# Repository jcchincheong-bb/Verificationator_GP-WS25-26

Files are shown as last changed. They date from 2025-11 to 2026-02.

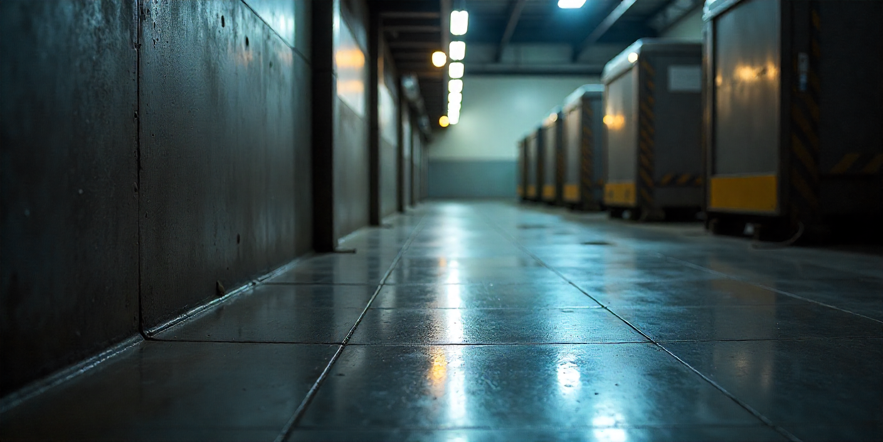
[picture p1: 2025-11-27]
3.8 Interactive Brochure (and Spec Sheet)/assets/bg_factoryfloor.png

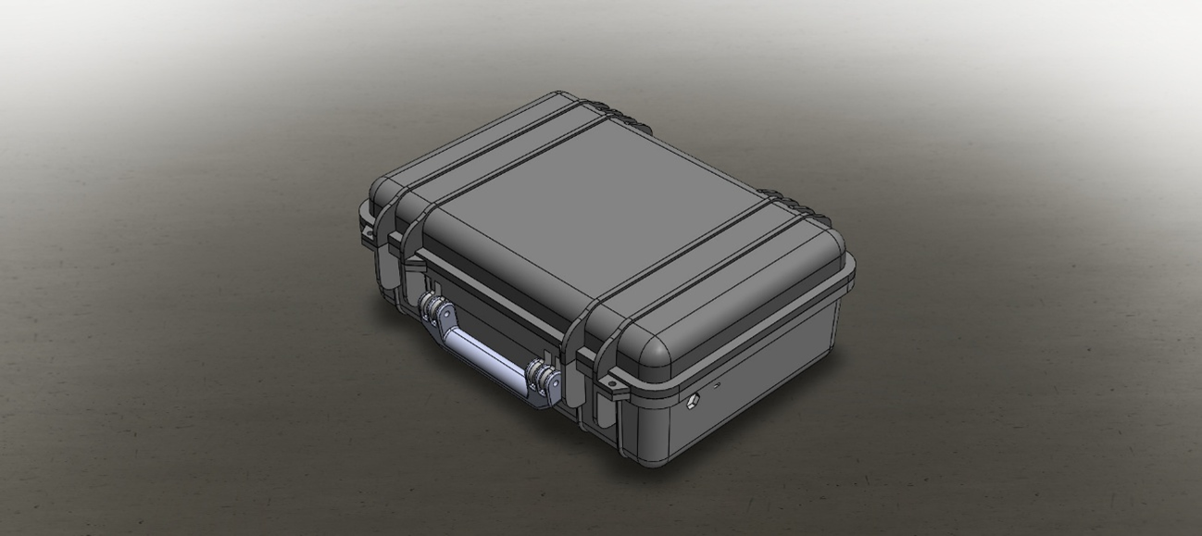
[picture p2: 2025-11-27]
3.8 Interactive Brochure (and Spec Sheet)/assets/PH_case_outside.png

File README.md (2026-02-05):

This project was done as part of the Group Project Module at HSRW in WS25/26. It was done under requirements provided by [Innovatest](https://www.innovatest-europe.com/). 

### Abstract
Product Showcase (https://www.youtube.com/watch?v=Xx_LVumxhoE)

The Verificationator project is focused on the design of a highly portable, robust, and user-friendly solution that allows technicians to verify and calibrate hardness testers directly in the field. The project’s scope spans from the concept design to the project documentation and the design of an interactive brochure. The project spanned from October 5th, 2025, to January 13th, 2026. Five engineering students make up the interdisciplinary design team, and the project was completed under the guidance of Hochschule Rhein-Waal professors and scientific staff.

Initial market analysis revealed that the market for hardness testers is growing and ready for such a portable verification kit. The initial concept proposed a fully integrated system which can operate safely in factory environments, has an ergonomic HMI, and can automatically identify and operate with Innovatest load cell models ranging from 10 gf to 3,000 kgf. The production budget was set to €4,000 per unit, ensuring competitiveness on the market.

From a mechanical standpoint, the device uses an IP-67 rated rugged pelican case with an aluminium chassis mounted inside to house the electronics. Medium density foam inserts surround this chassis to provide shock absorption and padding. Load cells are stored in dedicated foam compartments on the opposite side of the case, allowing secure transport without damage or misalignment. A complete 3D model was constructed to demonstrate all mechanical connections, fasteners, sealants, and other features to create a device that is suited for harsh factory environments. To document the entire mechanical design, a technical assembly drawing was done according to DIN 406.

On the electrical side of the design, a complete schematic diagram and preliminary PCB were designed to match all functionality requirements with the utmost precision and speed. An advanced measurement chain was designed to process the load cell signals and gives a noise-free resolution of 17 bits, classifying as a Class A measuring device by OIML. The design also incorporates high-performance components such as the ESP32-P4, allowing for incredible signal processing and input responsiveness. The control, power management, and battery management circuits were designed to give a battery life of 9.16 hours and advanced features such as switching between 5 V and 10 V excitation and real-time graphing. The complete program logic of the microcontroller is documented in a programming flow chart to illustrate the main settings, interrupts, and other processes.

After a Make or Buy analysis was performed, the pelican case and electrical components were specified in the requirements manual, and the custom-made aluminium and foam interior manufacturing techniques were defined. A complete BOM was then done after careful selection of components. After which, the complete production and assembly plan was defined, revealing a takt time of 756 min/unit and a total production time of 1032 min/unit, suggesting parallel manufacturing or outsourcing may be required. The assembly time, on the other hand, was found to be only 142 min/unit.

Finally, the costs of all the materials, labour, manufacturing, and overheads were considered to calculate a production cost of €3990.15. Accounting for business overheads, profit, and commission, the final offer price was found to be €7018.28.

### Development Team
- [Abhinav Kothari](https://www.linkedin.com/in/abhinav-kothari-2ak/) - Manufacturing and Production Planning, Video Editing
- Ahmad Zeaiter - Mechanical Design, Technical Drawing, Brochure Design
- [Justin Julius Chin Cheong](https://jcchincheong-bb.github.io/) - Project Managment, Market Analysis, Cost Estimation, System Architecture and Signal Conditioning Design
- Wasim Ahmed Mohammed Al Asbahi - Main Electrical Design, Programming Flowchart

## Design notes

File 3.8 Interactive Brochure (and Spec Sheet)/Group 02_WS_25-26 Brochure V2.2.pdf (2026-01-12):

# VERFICATIONATOR

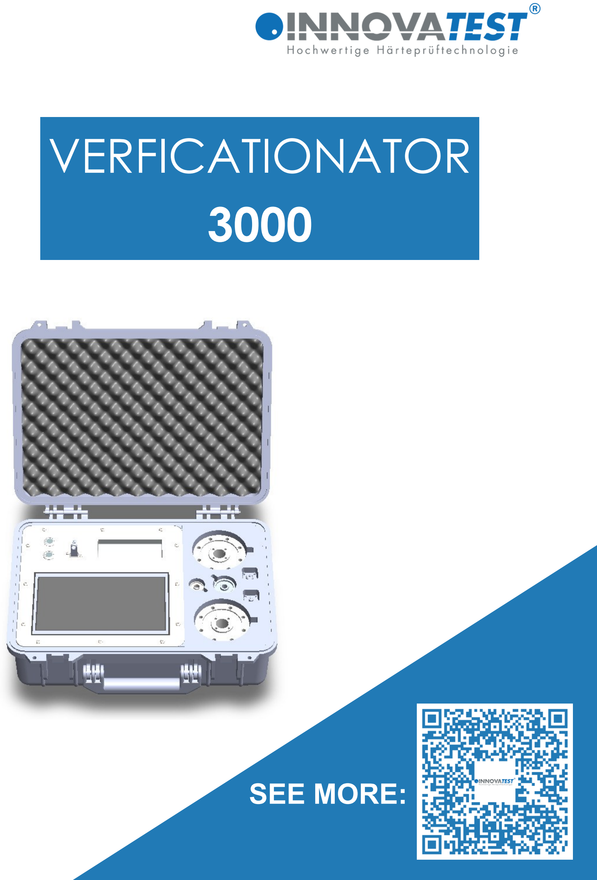
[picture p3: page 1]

3000

# SEE MORE:

The Verificationator 3000 is a premier load cell calibration device that works with 6 load cells, promises incredible precision, low noise and easy to use calibration of the load cells. With such a device, laboratory calibration can become a thing of the past, as with high mobility and rugged design, the kit can be taken to any job site in any conditions to verify the force output of Innovatest hardness testers using Innovatest load cells.

# VERF-3000

# Mobile and Portable

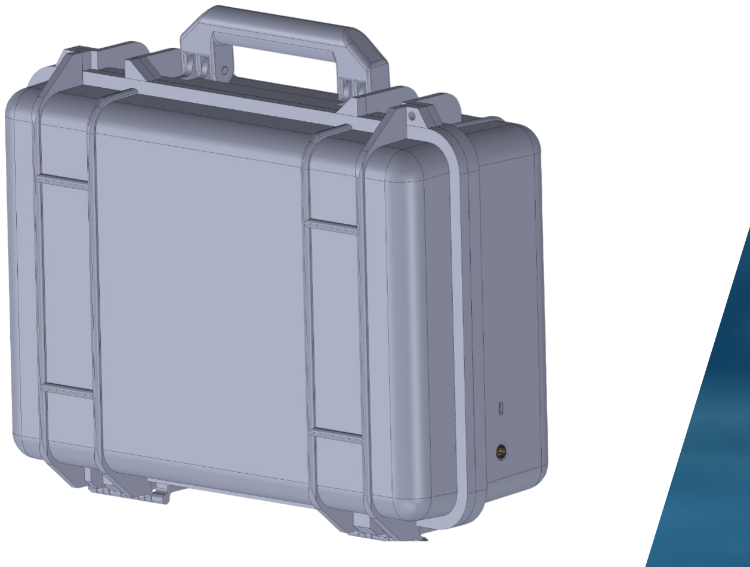
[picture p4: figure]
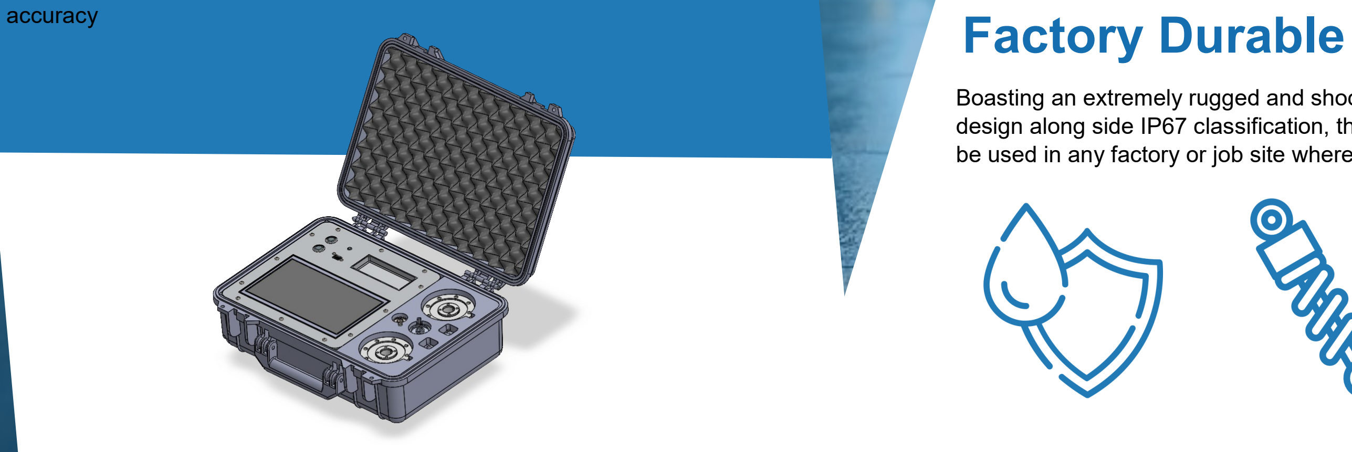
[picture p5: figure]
accuracy; Factory Durable

Boasting an extremely rugged and shock absorbent design along side IP67 classification, the VERF-3000 can be used in any factory or job site where needed.

# The Verificationator 3000

# Extreme Precision

With enough precision to be a OIML Class A load cell measuring device, the VERF-3000 can ensure load cells are calibrated to the upmost precision and

The Verificationator 3000 is mobile and lightweight and can be carried anywhere it is needed.

Weighing only 12kg, it is a revolutionary step in force verification on the go

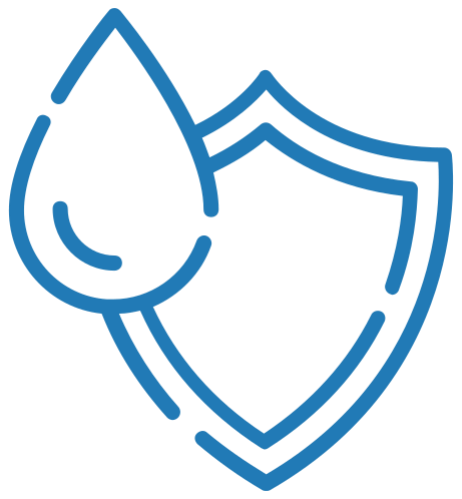
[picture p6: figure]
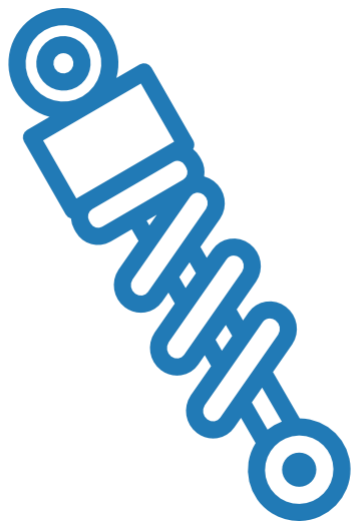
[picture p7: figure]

Main Features The Verificationator 3000 can be easily used to measure the force values for calibration or testing or routine inspections. The data is plotted on a graph and exportable to a USB stick in a CSV format

# TOUCH SCREEN

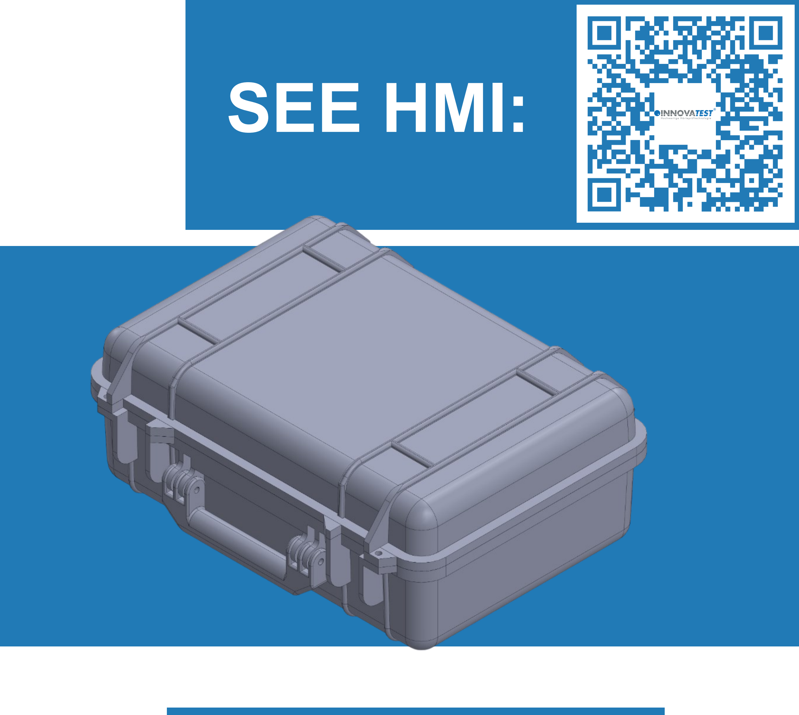
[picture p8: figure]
SEE HMI:

Real-Time Graphing | Export to CSV

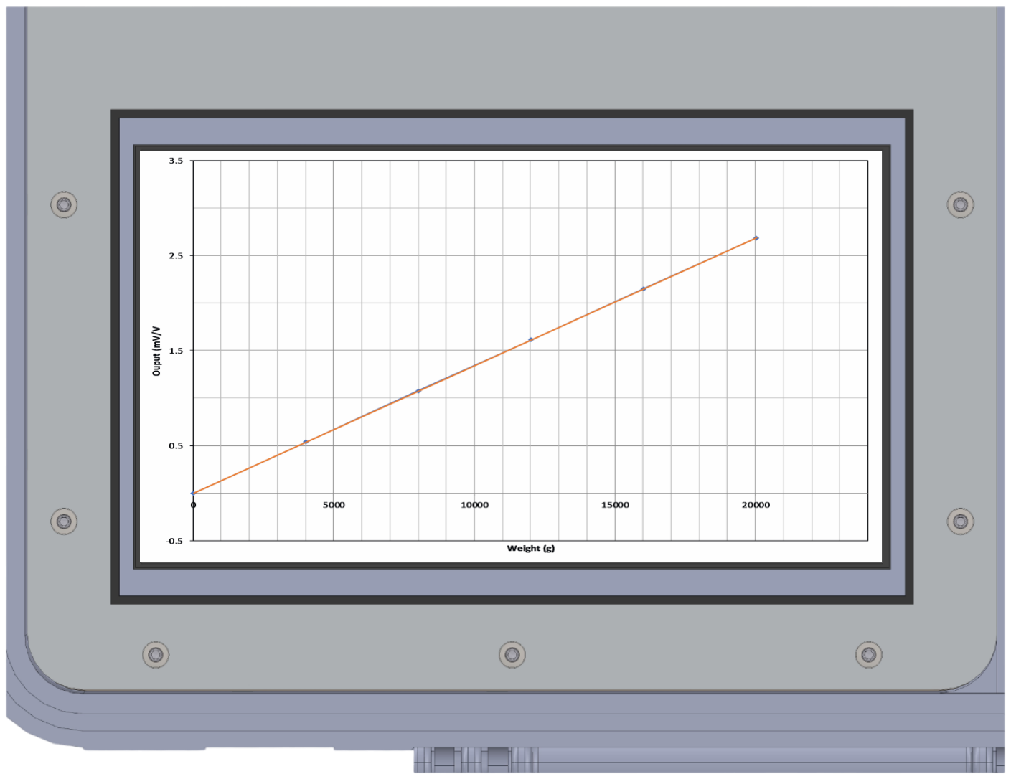
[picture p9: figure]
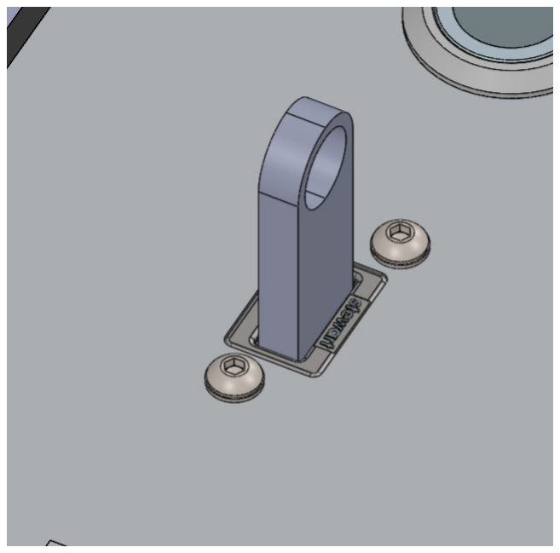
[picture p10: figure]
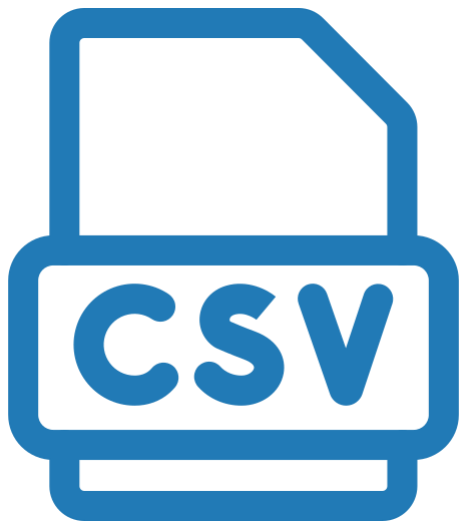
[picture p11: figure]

# Long-lasting & Rechargeable

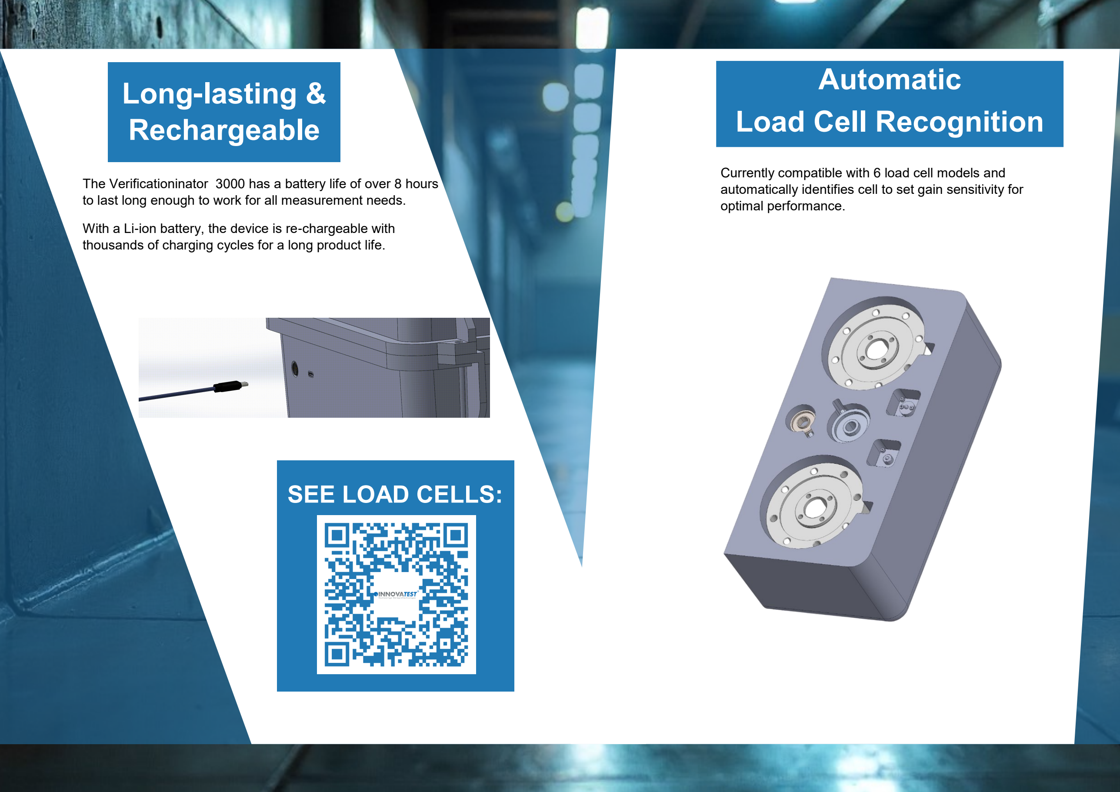
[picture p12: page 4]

The Verificationinator 3000 has a battery life of over 8 hours to last long enough to work for all measurement needs.

With a Li-ion battery, the device is re-chargeable with thousands of charging cycles for a long product life.

Currently compatible with 6 load cell models and automatically identifies cell to set gain sensitivity for optimal performance.

# Automatic Load Cell Recognition

# SEE LOAD CELLS:

# Spec. Sheet STANDARD

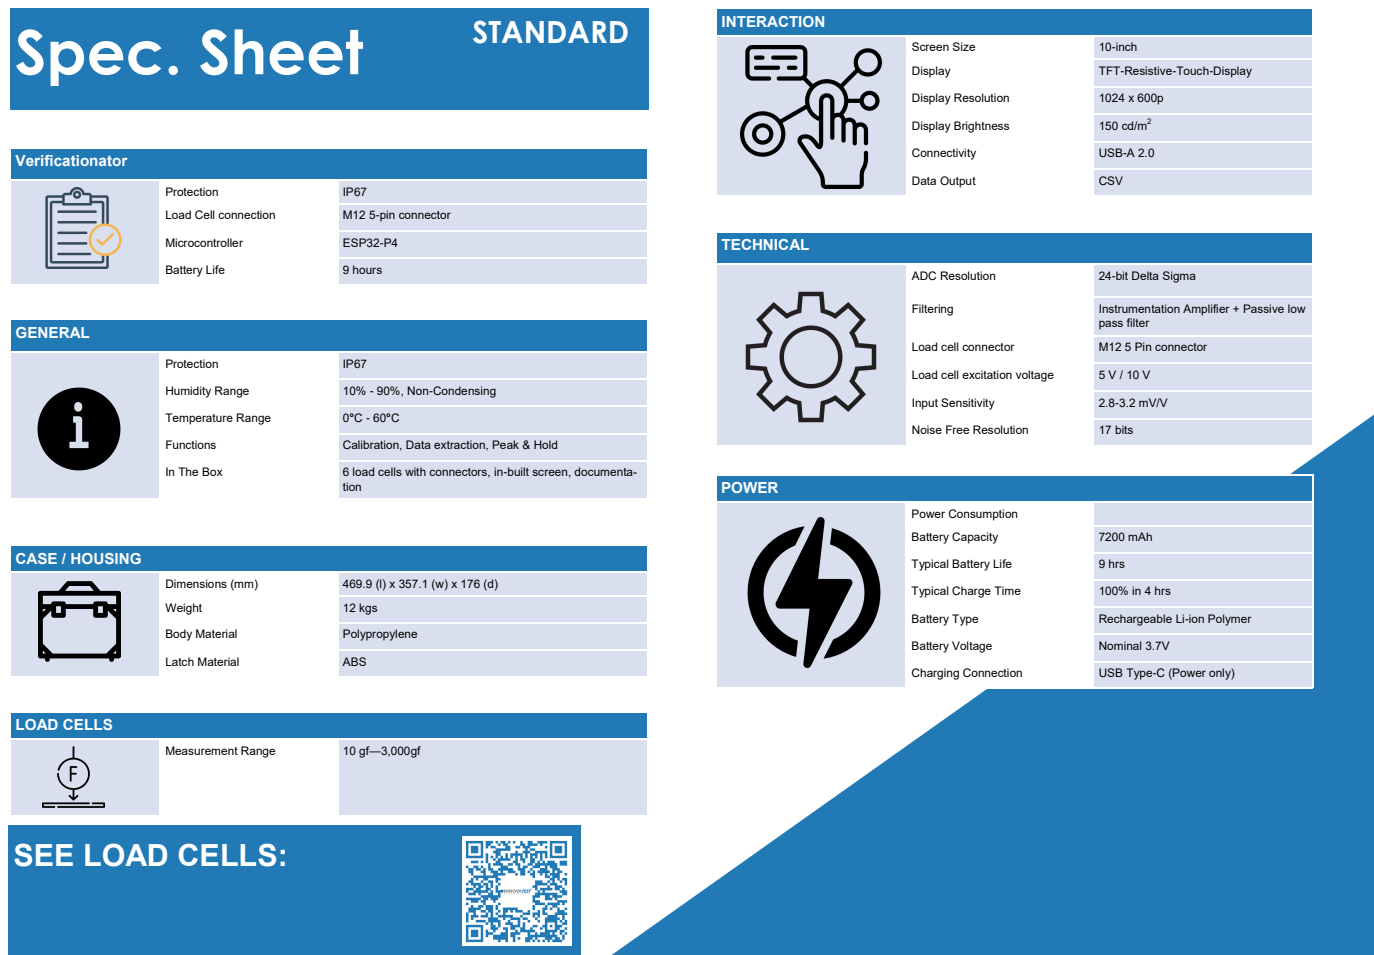
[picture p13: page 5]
Verificationator; Microcontroller; ESP32-P4; Battery Life; 9 hours; CASE / HOUSING; GENERAL; INTERACTION; LOAD CELLS; Measurement Range; TECHNICAL; POWER

Screen Size | 10-inch

Display | TFT-Resistive-Touch-Display

Display Resolution | 1024 x 600p

Display Brightness | 150 cd/m²

Connectivity | USB-A 2.0

Data Output | CSV

Protection | IP67

Load Cell connection | M12 5-pin connector

ADC Resolution | 24-bit Delta Sigma

Filtering | Instrumentation Amplifier + Passive low pass filter

Load cell connector | M12 5 Pin connector

Load cell excitation voltage | 5 V / 10 V

Humidity Range | 10% - 90%, Non-Condensing

Input Sensitivity | 2.8-3.2 mV/V

Temperature Range | 0°C - 60°C

Noise Free Resolution | 17 bits

Functions | Calibration, Data extraction, Peak & Hold

In The Box | 6 load cells with connectors, in-built screen, documenta-tion

Power Consumption

Battery Capacity | 7200 mAh

Typical Battery Life | 9 hrs

Dimensions (mm) | 469.9 (l) x 357.1 (w) x 176 (d)

Typical Charge Time | 100% in 4 hrs

Weight | 12 kgs

Battery Type | Rechargeable Li-ion Polymer

Body Material | Polypropylene

Battery Voltage | Nominal 3.7V

Latch Material | ABS

Charging Connection | USB Type-C (Power only)

SEE LOAD CELLS:

Development Team:

Ahmad Zeaiter

Abhinav Kothari

Justin Julius Chin Cheong

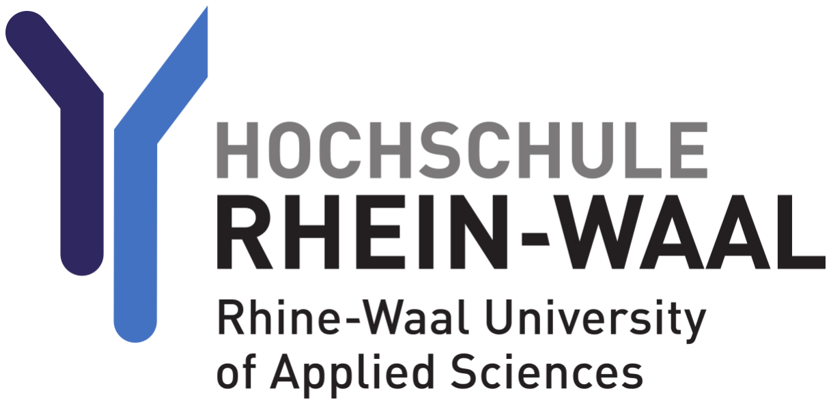
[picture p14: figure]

Wasim Ahmed Mohammed Al Abashi

Okan Can Meral

Contact Person:

abhinav.kothari@hsrw.org

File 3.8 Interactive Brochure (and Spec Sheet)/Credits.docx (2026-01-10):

# CREDITS

Brochure Design Ahmad Zeaiter

Interactivity Justin Julius Chin Choeng

User Manual Okan Can Meral

Video Editing Abhinav Kothari

# MADE WITH

SolidWorks Modeling & Assembly Animation

Veo 3 Product Concept Video Generation

Clipchamp Video Editing Software

Flaticon Icons

LEGAL NOTICE: This brochure includes video content generated using artificial intelligence (Google Veo 3 / Gemini). All AI-generated assets were created in compliance with Google’s Generative AI Terms of Service. The creator retains ownership rights to the generated output as per the platform's commercial usage policy.

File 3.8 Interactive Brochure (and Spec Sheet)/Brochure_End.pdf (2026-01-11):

Development Team:

Ahmad Zeaiter

Abhinav Kothari

Justin Julius Chin Cheong


Wasim Ahmed Mohammed Al Abashi

Okan Can Meral

Contact Person:

abhinav.kothari@hsrw.org

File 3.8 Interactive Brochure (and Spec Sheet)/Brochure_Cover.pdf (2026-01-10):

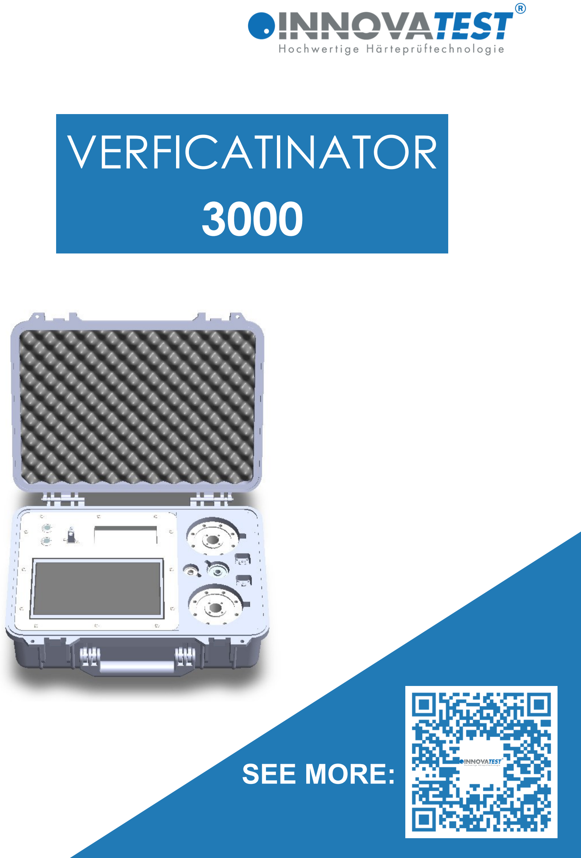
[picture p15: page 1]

VERFICATINATOR
3000

SEE MORE:

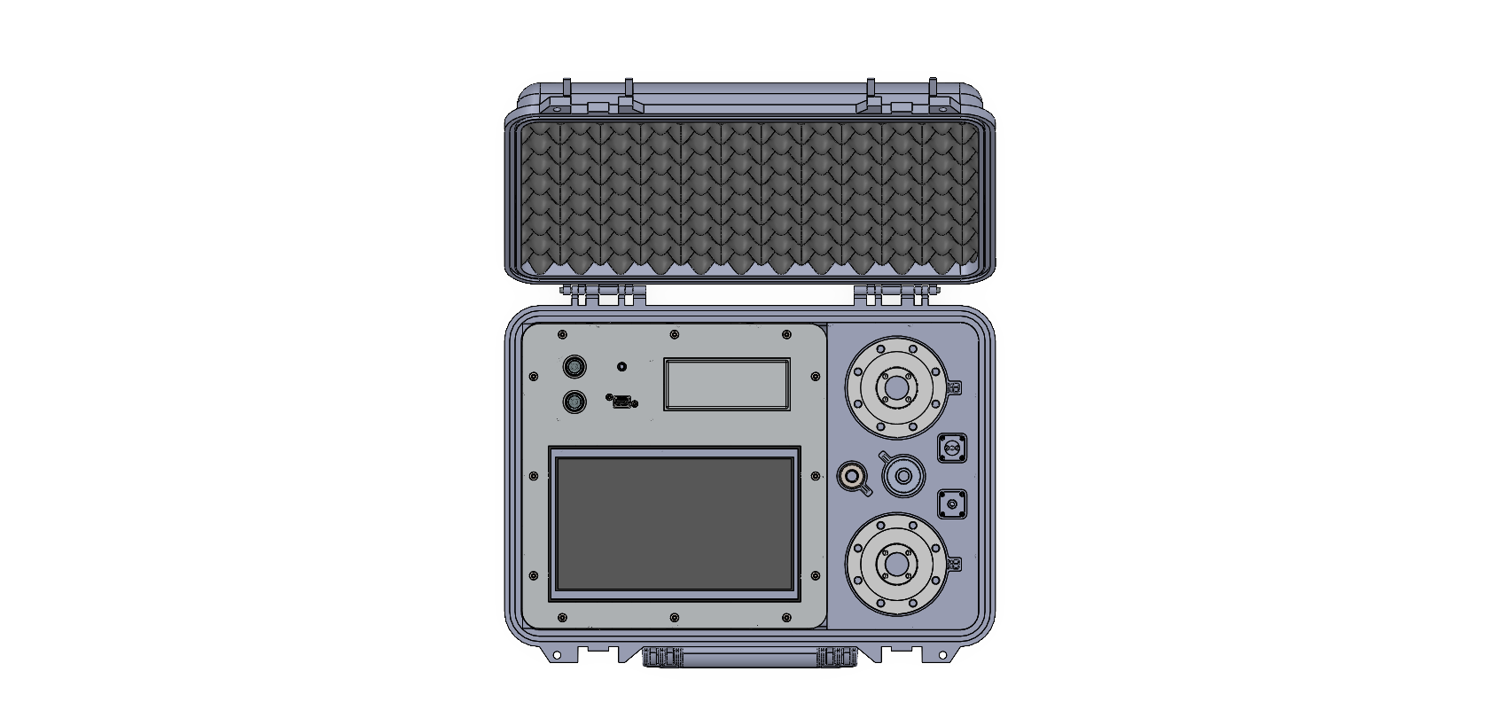
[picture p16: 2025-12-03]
3.8 Interactive Brochure (and Spec Sheet)/assets/top-view.PNG

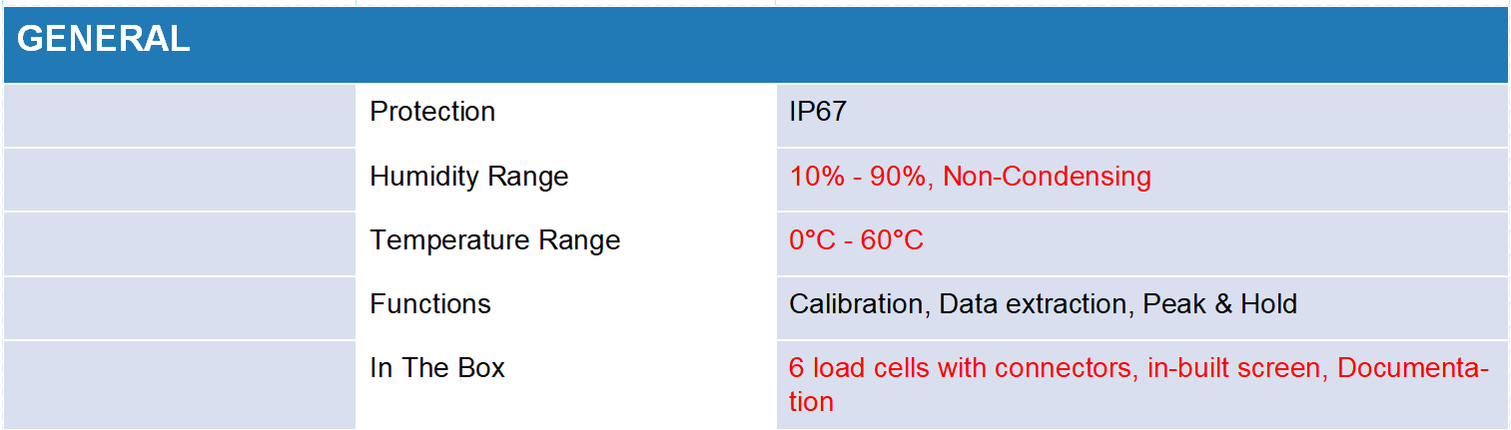
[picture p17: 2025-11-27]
3.8 Interactive Brochure (and Spec Sheet)/assets/general.PNG

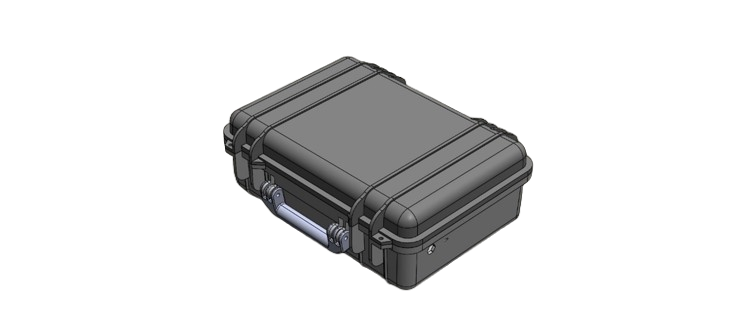
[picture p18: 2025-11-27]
3.8 Interactive Brochure (and Spec Sheet)/assets/PH_case_outside_transparent.png

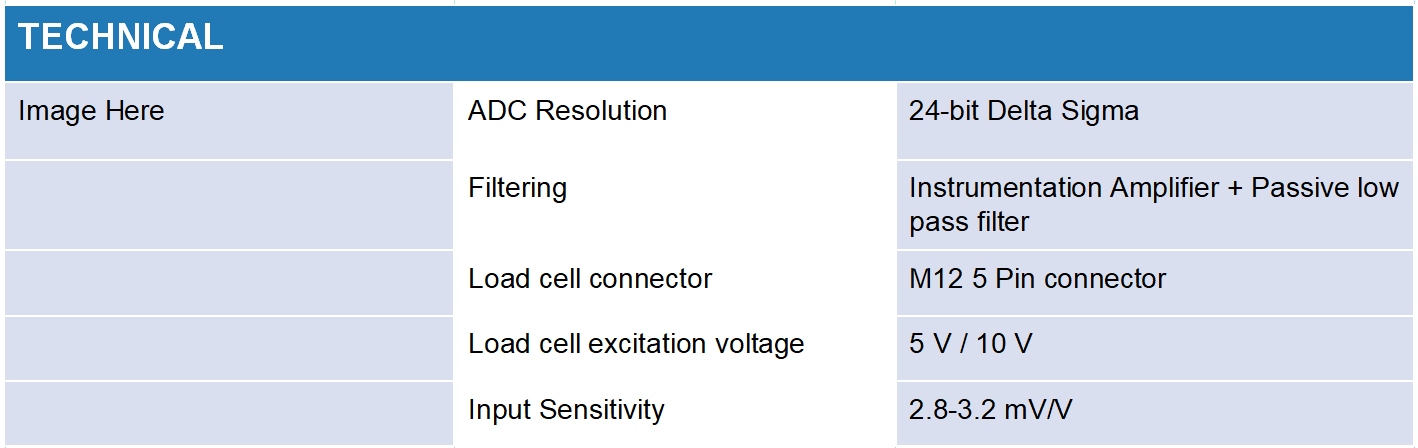
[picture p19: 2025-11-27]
3.8 Interactive Brochure (and Spec Sheet)/assets/technical.PNG

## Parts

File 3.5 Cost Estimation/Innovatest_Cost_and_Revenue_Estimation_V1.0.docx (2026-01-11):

# Direct Material Costs

Subsystem | Key Components | Function | Cost [€]
Processing & Control | MCU, Flash Memory | System control & communication | 5
Measurement Chain | ADC, Amplifiers, Filters | Precision force measurement | 15
HMI | Touchscreen, LEDs, Buttons | User interaction & status indication | 30
Power System | Battery, Regulators | Portable power supply | 10
PCB & Passives | PCB, resistors, capacitors | Electrical integration | 14
Protective Case | Pelican Case | Structural Housing | 220
Miscellaneous Mechanical Components | Screws, fasteners, glue, O-rings | Mechanical securing and sealing | 10
Load Cells | 6 Innovatest load cells | Force measurement | 2844
Total Direct Material Cost: | | | 3148

# Raw Material Costs

Material | Quantity [kg] | Cost per kg [€/kg] | Cost [€]
Polycarbonate | 0.12 | 3.5 | 0.42
ABS | 0.08 | 2.5 | 0.2
5052 Aluminum | 6.6 | 4 | 26.4
EVA/PU Foam | 0.96 | 2 | 1.92
Total Raw Material Cost: | | | 28.94

# 7. Material Overhead Costs

Material Overhead Rate = 5%

Material Overhead Costs = 5% * (Direct Material Costs + Raw Material Costs)

= 5% * (€3148 + €28.94) = €158.85

Therefore, the total material costs = €3148 + €28.94 + €158.85 = €3335.79/unit

# 8. Manufacturing Labor Costs

Assuming an hourly wage of €20/h, the labour costs can be calculated using the total working hours found in :

Total Annual Labor Costs = 4284h/year * €20/h = €85 680/year

Unit Labor Cost = €85 680/year ÷150 unit/year = €571.20/unit

# 9. Production Overheads

## 9.1 Machine Depreciation

To calculate the machine costs, the annual depreciation rate had to be considered to find the depreciation per year. Then, considering that the machines availability as found in Table , the machine hourly rates were found. Finally, the required machine hours per unit from Table, we used to calculate the machinery costs per unit.

Machine | Total Cost [€] | Annual Depreciation Rate | Depreciation Per Year [€/year] | Machine Hourly Rate [€/h] | Machine Hours per Unit [h/unit] | Machine Cost per Unit [€/unit]
3D Printer | 800 | 20% | 160 | 0.1539 | 6.7 | 1.03
4-Axis CNC Milling Machine | 70000 | 10% | 7000 | 5.2910 | 2.72 | 14.37
3-Axis CNC Contour Machine | 50000 | 10% | 5000 | 4.0700 | 2.22 | 9.02
3-Axis CNC Milling Machine | 9000 | 10% | 900 | 0.6803 | 1.58 | 1.077
Extrusion Press | 100000 | 10% | 10000 | 5.8789 | 0.28 | 1.67
Drill | 150 | 10% | 15 | 0.0132 | 0.23 | 0.00309
Reamer | 30 | 10% | 3 | 0.0032 | 0.27 | 0.0008466
Laser Cutter | 40000 | 10% | 4000 | 3.0234 | 0.42 | 1.260
Welding Plant | 500 | 10% | 50 | 0.0529 | 1.28 | 0.0679
Automated Pick-and-Place Machine | 3500 | 10% | 350 | 0.2469 | 0.18 | 0.04527
Reflow Oven | 360 | 5% | 18 | 0.0112 | 0.34 | 0.00383
Hand Soldering Station | 200 | 5% | 10 | 0.0151 | 0.42 | 0.00630
Total | | | | | | 28.56

## 9.2 Utilities

Machine | Power [kW] | Cost per kWh [€/kWh] | Machine Hours per Unit [h/unit] | Utility Cost per Unit [€/unit]
3D Printer | 0.15 | 0.04 | 6.70 | 0.04
4-Axis CNC Milling Machine | 8 | 2.1 | 2.72 | 45.64
3-Axis CNC Contour Machine | 2.7 | 2 | 2.22 | 11.97
3-Axis CNC Milling Machine | 1 | 2 | 1.58 | 3.17
Extrusion Press | 10 | 0.8 | 0.28 | 2.27
Drill | 0.05 | 0.02 | 0.23 | 0.00023
Reamer | 0 | 0 | 0.27 | 0
Laser Cutter | 4.5 | 1.17 | 0.42 | 2.19
Welding Plant | 2.5 | 0.65 | 1.28 | 2.09
Automated Pick-and-Place Machine | 0.2 | 0.05 | 0.18 | 0.00183
Reflow Oven | 1.2 | 0.31 | 0.34 | 0.13
Hand Soldering Station | 0.07 | 0.02 | 0.42 | 0.00058
Total | | | | 67.49

## 9.3 Factory Rent Allocation

Based on the requirements the facility size needed is estimated to be around 100 square meters and estimated rent is 7 euros per square meters.

Monthly Base Rent: 100m^2*€ 7/m^2 = €700/month

Yearly Base Rent: €700/month * 12 month/year = €8400/year

Additional Costs = €8400/year * 15% = €1260/year

Total Annual Rent = €8400/year + €1260/year = €9660/year

Rent per Unit = €9660/year ÷ 150 unit/year = €64.40/unit

## 9.4 Total Production Overhead

Therefore our total manufacturing costs =

= €571.20/unit + €28.56/unit + €67.49/unit + €64.40/unit = €731.65/unit

# 10. Total Production Costs

Therefore the total production costs:

€3335.79/unit + €731.65/unit = €4067.44/unit

While this is slightly above the budget outlined in Section, the main contributor to costs is the labour costs. If manufacturing of some parts are outsourced, this can potentially reduce the costs sufficiently enough to stay within the allocated €4000/unit budget.

# 11. Overheads

To account for administrative and marketing and sales overhead, we use simple margin percentages of 8% and 15% respectively.

Admin Overhead = 8% * €4067.44/unit = €325.39/unit

Marketing overhead = 15% * €4067.44/unit = €610.12/unit

Therefore,

COGS = €4067.44/unit + €325.39/unit + €610.12/unit = €5002.95/unit

Finally, to calculate a reasonable offer price, we can use a 25% profit margin

Proft = 25% * €5002.95/unit = €1500.88/unit

Cash Selling Price = €5002.95/unit + €1500.88/unit = €6503.83/unit

With a distributor commission of around 10%,

Commission = 10% * €6503.83/unit = €650.38/unit

Therefore,

FINAL OFFER PRICE = €7154.21/unit

# 14. Summary

A target profit margin is applied to the cost of goods sold to determine the final selling price. This margin ensures sustainability while maintaining market competitiveness.

Item | Value
Material Costs | €3335.79
Manufacturing Costs | €731.65
Production Costs | €4067.44
COGS | €5002.95
Cash Selling Price | €6503.83
Proft | €1500.88
Final Offer Price | €7154.21

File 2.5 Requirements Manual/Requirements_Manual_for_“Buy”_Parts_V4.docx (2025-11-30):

2.5 Requirements Manual for “Buy” Parts

2.5.1 Categorise “buy” parts into mechanical and electrical

Electrical BUY Parts

1. Microcontroller (MCU)
2. Load Cell Connector
3. Load Cell Interface Port
4. Noise and Low-pass Filter
5. Amplifier
6. Analog to Digital Converter (ADC) Module
7. Cell Excitation Regulator
8. Touchscreen Display
9. Latching Push Button
10. Internal Memory Module
11. USB-A Port
12. Power Regulator
13. USB-C Port
14. Battery Charging Circuit
15. Battery
16. Misc

Total Electrical Buy Parts: 16

Mechanical BUY Parts

1. Protective Carrying Case
2. Foam
3. 1-Panel Frame
4. M4 x 12 Button Head Screw
5. M3 x 10 Button Head Screw
6. M3 x 8 Button Head Screw
7. ST3.5x9.5 Tapping Screw
8. M3 Hex Nuts
9. M4 Washer
10. M3 Washer
11. Roll 20mm Wide Velcro
12. PVC Foam Tape
13. M4X9.2

Total Mechanical Buy Parts: 13

Total BUY parts = 29

2.5.2 Table for Buy parts

Electrical parts

No. | Part | Qty. | Requirements | | Justification
1 | Microcontroller (MCU) | 1 | - 5 V operation; ≥16 MHz clock; - 32 kB Flash, 2 kB SRAM; SPI/I²C/UART interfaces; - industrial temperature −40…85 °C. | | With a committed MCU, deterministic timing for ADC sampling is made possible and steady handling of user interface, force computations, and communication procedures is guaranteed—something non-real-time processors would not be dependable with.

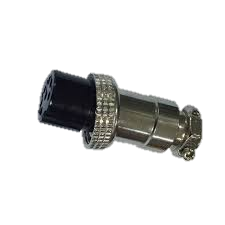
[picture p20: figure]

2 | Load Cell Connector | 1 | - Shielded multi-core cable; - compatible with Innovatest load-cell wiring; - PVC/PUR jacket; - −25…80 °C temperature rating; - low-resistance copper conductors. | | By lowering EMI coupling and guaranteeing a physically secure link under field vibrations, a devoted shielded connector helps to preserve high signal integrity.

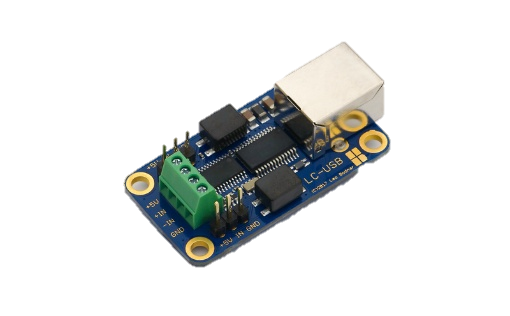
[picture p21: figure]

3 | Load Cell Interface Port | 1 | - Panel-mount 5-contact connector; - IP67 protection; nickel-plated brass/PA housing; - rated current ≥ 2 A; - screw-lock interface. | | Applying an industrial M12 interface guarantees IP67 sealing and ensures consistent pin mapping for every Innovatest load cell, therefore minimizing wiring mistakes.
4 | Noise and Low-pass Filter | 1 | - RC/passive low-pass filter; - cutoff frequency 5–20 Hz; - 1–5 % tolerance components; - low-noise conditioning for mV-level signals. | | The use of passive filter allows for greater stability and reliability than active ones. Ensuring only frequencies below 5-20Hz pass eliminates most high frequency noise from the load cell.
5 | Amplifier | 1 | - Differential instrumentation amplifier; - gain ≥1000×; CMRR ≥100 dB; input offset <50 µV; - input noise density <10 nV/√Hz. | | With little drift, a precision instrumentation amplifier guarantees correct differential signal amplification that is absolutely necessary for sub-millivolt load-cell outputs.

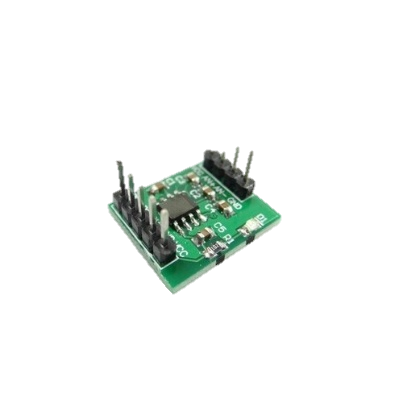
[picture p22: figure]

6 | Analog to Digital Converter (ADC) Module | 1 | - 24-bit delta-sigma ADC; - differential inputs; - SPI interface; - effective resolution ≥18 bits; - input noise <1 µV RMS. | | For low load-cell output changes and stable digital conversion with reduced quantization noise, a 24-bit ADC offers the necessary resolution.
7 | Cell Excitation Regulator | 1 | - Selectable 5 V / 10 V excitation; - ripple <10 mVpp; load current ≥50 mA; - regulation error <1 %. | | Consistent load-cell sensitivity and linearity are guaranteed by a controlled 5/10 V excitation, which also avoids measurement variance caused by supply drift.

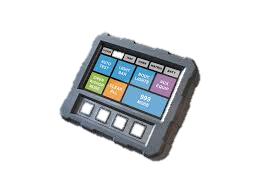
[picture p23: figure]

8 | Touchscreen Display | 2 | - 10.1″ TFT; 1024×600 resolution; 4-wire resistive touch; - ≥300 cd/m² brightness; 5 V supply; - SPI/parallel interface. | | While a vivid TFT panel guarantees visibility in different lighting conditions during field use, a resistive touchscreen allows for precise control even with gloves.
9 | Latching Push Button | 1 | - Panel-mount latching switch; - IP65 front; ≥1 A @ 24 VDC; - electrical endurance ≥30 000 cycles.

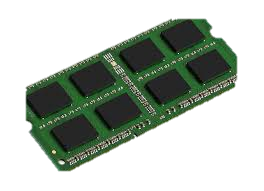
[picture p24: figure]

10 | Internal Memory Module | 1 | - ≥8 MB SPI-NOR Flash; - 3.3 V operation; ≥100k P/E cycles; - data retention ≥20 years. | | Onboard non-volatile memory offers safe data logging independent of continuous power or external devices.
11 | USB-A Port | 1 | - USB-A female connector; - USB 2.0 compliant; - rated ≥500 mA; - insertion life ≥1500 cycles. | | A USB-A interface provides universal compatibility for exporting calibration data across service environments.
12 | Power Regulator | 3 | - Linear/DC-DC regulator stage; - 5 V and/or 3.3 V /5.5V/10V outputs; - ripple <20 mV; - regulation <2 %; - continuous output ≥500 mA. | | Dedicated low-ripple regulators maintain stable 5 V and 3.3 V rails, therefore preventing noise injection into delicate analog circuitry.
13 | USB-C Port | 1 | - USB-C receptacle; - 5 V input; - mechanical retention ≥8 N; - compliant with USB Type-C geometry. | | A USB-C charging interface ensures compatibility with modern power sources and guarantees safe current handling.
14 | Battery Charging Circuit | 1 | - Li-Ion CC/CV charging circuit; - 5 V USB-C input; - charge current up to 1 A; - integrated OV/OC/OT protection. | | A dedicated Li-Ion charging IC ensures safe CC/CV charging behavior and prevents battery degradation or hazardous operation.

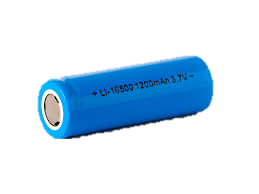
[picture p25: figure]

15 | Battery | 1 | - Li-Ion battery ≥5000 mAh; - discharge capability ≥2 A; - integrated protection (BMS); - IEC-compliant cell pack. | | A high-capacity Li-Ion battery ensures sufficient field autonomy, enabling extended operation without external power.
16 | Misc | 1 | - Mixed electronic passives: 1 % metal-film resistors; - X7R ceramic capacitors; - inductors with adequate Q-factor; - insulated copper wire rated ≥60 V and −20…80 °C; - 2.54 mm pin headers or board-to-wire connectors. | | Industry-standard passives and shielded wiring ensure stable analog performance, low noise, robust insulation, and reliable board-to-board interfacing.

Mechanical Parts

| | | | | Justification

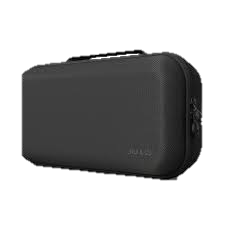
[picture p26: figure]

1 | Protective Carrying Case | 1 | - Polypropylene copolymer case; - IP67 rating; - pressure equalization valve; - internal dimensions ≥420×280×150 mm; - impact-resistant hinges and latches. | | A rugged IP67 case protects the entire system from dust, water, shock, and transport damage during field deployment.
2 | Foam | 1 | - EVA/PU foam inserts; density ≥30 kg/m³; - CNC/laser-cut cavities; - compression-set resistant; - thickness matched to internal case profile. | | Custom-cut EVA/PU foam provides precise support for each load cell and electronic component, minimizing vibration and mechanical stress.

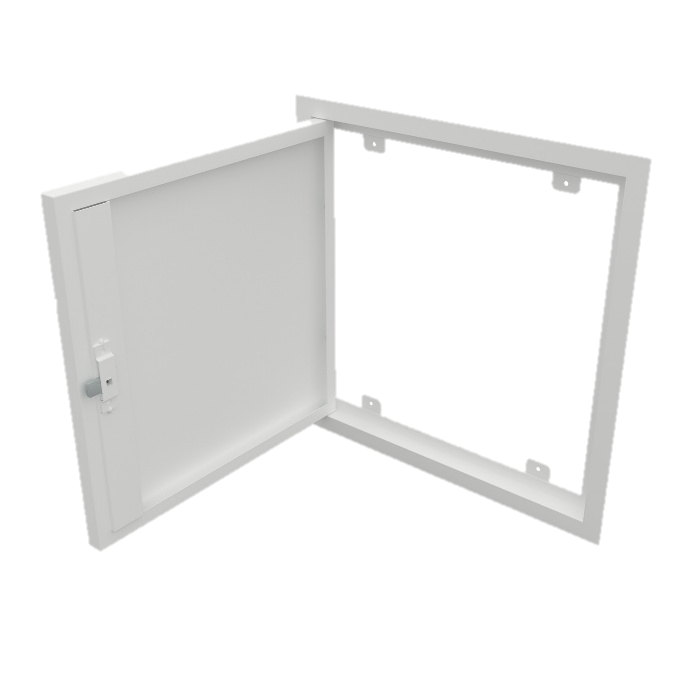
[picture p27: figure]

3 | 1-Panel Frame | 1 | - Aluminium/steel front panel; - 2–3 mm thickness; - anodized or powder-coated; - cut-outs for display, button, LED; - mounting pattern aligned with internal frame. | | A rigid front panel provides secure mounting for the display and controls, preventing misalignment and improving long-term usability.
4 | M4 x 12 Button Head Screw | 12 | - ISO 7380
7 | M3 x 10 Button Head Screw | 4 | - ISO 7380
8 | M3 x 8 Button Head Screw | 12 | - ISO 7380
9 | ST3.5x9.5 Tapping Screw | 4 | - DIN 7049
10 | M3 Hex Nuts | 16 | - ISO 4032
11 | M4 Washer | 12 | - ISO 7092
12 | M3 Washer | 16 | - ISO 7092
13 | Roll 20mm Wide Velcro | 1
14 | PVC Foam Tape | 1 | - 10mm Wide, - 2mm Thickness, - 1.16m
15 | M4X9.2 | 12 | - ACPTH 20 Zinc Plated

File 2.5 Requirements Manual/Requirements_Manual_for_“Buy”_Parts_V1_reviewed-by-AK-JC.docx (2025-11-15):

2.5.1 — Identification of All Necessary Buy Parts

1. Microcontroller (MCU)
2. Printed Circuit Board (PCB)
3. Load Cell Connector
4. Load Cell Interface Port
5. Noise and Low-pass Filter
6. Amplifier
7. Analog to Digital Converter (ADC) Module
8. Cell Excitation Regulator
9. Touchscreen Display
10. Latching Push Button
11. LED light
12. Internal Memory Module
13. USB-A Port
14. Power Regulator
15. USB-C Port
16. Battery Charging Circuit
17. Battery
18. Misc Electronics (Passives, Wires, Insulation, Pin headers)
19. Protective Carrying Case
20. Foam
21. 1-Panel Frame
22. Internal Aluminium Frame
23. Misc Mechanical (Screws, Fasteners, O-rings, Mounting brackets)
24. Load cells

2.5.2 Categorise “buy” parts into mechanical and electrical

Electrical BUY Parts

1. Microcontroller (MCU)
2. Printed Circuit Board (PCB) (the fabricated board is a buy item)
3. Load Cell Connector
4. Load Cell Interface Port
5. Noise and Low-pass Filter
6. Amplifier
7. Analog to Digital Converter (ADC) Module
8. Cell Excitation Regulator
9. Touchscreen Display
10. Latching Push Button
11. LED light
12. Internal Memory Module
13. USB-A Port
14. Power Regulator
15. USB-C Port
16. Battery Charging Circuit
17. Battery
18. Misc

Total Electrical Buy Parts: 18

Mechanical BUY Parts

1. Protective Carrying Case
2. Foam
3. 1-Panel Frame
4. Internal Aluminium Frame
5. Misc (Screws, Fasteners, O-rings, Mounting brackets)
6. Load cells

Total Mechanical Buy Parts: 6

Total BUY parts = 24

Requirements Manual for “Buy” Parts

No. | Part | Qty. | Requirements | | Justification


1 | Microcontroller (MCU) | 1 | 5 V operation; ≥16 MHz clock; 32 kB Flash, 2 kB SRAM; SPI/I²C/UART interfaces; industrial temperature −40…85 °C.


2 | Printed Circuit Board (PCB) | 1 | FR4 substrate; 1.6 mm thickness; 2–4 copper layers; 1 oz Cu; minimum track/space 0.2 mm; via diameter ≥0.3 mm; ENIG or HASL finish.


3 | Load Cell Connector | 1 | Shielded multi-core cable; compatible with Innovatest load-cell wiring; PVC/PUR jacket; −25…80 °C temperature rating; low-resistance copper conductors.


4 | Load Cell Interface Port | 1 | Panel-mount 5-contact connector; IP67 protection; nickel-plated brass/PA housing; rated current ≥2 A; screw-lock interface.
5 | Noise and Low-pass Filter | 1 | RC/active low-pass filter; cutoff frequency 5–20 Hz; 1–5 % tolerance components; low-noise conditioning for mV-level signals. | | The use of passive filter allows for greater stability and reliability than active ones. Ensuring only frequencies below 5-20Hz pass eliminates most high frequency noise from the load cell.


6 | Amplifier | 1 | Differential instrumentation amplifier; gain ≥1000×; CMRR ≥100 dB; input offset <50 µV; input noise density <10 nV/√Hz.


7 | Analog to Digital Converter (ADC) Module | 1 | 24-bit delta-sigma ADC; differential inputs; SPI interface; effective resolution ≥18 bits; input noise <1 µV RMS.
8 | Cell Excitation Regulator | 1 | Selectable 5 V / 10 V excitation; ripple <10 mVpp; load current ≥50 mA; regulation error <1 %.


9 | Touchscreen Display | 2 | 10.1″ TFT; 1024×600 resolution; 4-wire resistive touch; ≥300 cd/m² brightness; 5 V supply; SPI/parallel interface.


10 | Latching Push Button | 1 | Panel-mount latching switch; IP65 front; ≥1 A @ 24 VDC; electrical endurance ≥30 000 cycles.


11 | LED light | 1 | High-brightness LED ≥1000 mcd; forward voltage 2–3 V; daylight-readable output; panel-mount type.


12 | Internal Memory Module | 1 | ≥8 MB SPI-NOR Flash; 3.3 V operation; ≥100k P/E cycles; data retention ≥20 years.
13 | USB-A Port | 1 | USB-A female connector; USB 2.0 compliant; rated ≥500 mA; insertion life ≥1500 cycles.
14 | Power Regulator | 1 | Linear/DC-DC regulator stage; 5 V and/or 3.3 V outputs; ripple <20 mV; regulation <2 %; continuous output ≥500 mA.
15 | USB-C Port | 1 | USB-C receptacle; 5 V input; mechanical retention ≥8 N; compliant with USB Type-C geometry.
16 | Battery Charging Circuit | 1 | Li-Ion CC/CV charging circuit; 5 V USB-C input; charge current up to 1 A; integrated OV/OC/OT protection.


17 | Battery | 1 | Li-Ion battery ≥5000 mAh; discharge capability ≥2 A; integrated protection (BMS); IEC-compliant cell pack.
18 | Misc | 1 | Mixed electronic passives: 1 % metal-film resistors; X7R ceramic capacitors; inductors with adequate Q-factor; insulated copper wire rated ≥60 V and −20…80 °C; 2.54 mm pin headers or board-to-wire connectors.

| | | | | Justification


1 | Protective Carrying Case | 1 | Polypropylene copolymer case; IP67 rating; pressure equalization valve; internal dimensions ≥420×280×150 mm; impact-resistant hinges and latches.
2 | Foam | 1 | EVA/PU foam inserts; density ≥30 kg/m³; CNC/laser-cut cavities; compression-set resistant; thickness matched to internal case profile.


3 | 1-Panel Frame | 1 | Aluminium/steel front panel; 2–3 mm thickness; anodized or powder-coated; cut-outs for display, button, LED; mounting pattern aligned with internal frame.
4 | Internal Aluminium Frame | 1 | Aluminium internal frame; yield strength ≥150 MPa; profiles/sheets supporting PCB, battery, and display; corrosion-protected; vibration-stable structure.
5 | Misc | N./a. | DIN-compliant fasteners (M3–M6); stainless-steel A2/A4 or zinc-plated steel; washers and nuts to EN standards; NBR/EPDM O-rings; steel/aluminium brackets (2–4 mm).


6 | Load cells | 6 | Innovatest load cells; capacity range 150 gf–3000 kgf; full Wheatstone bridge; rated output ≤4 mV/V; excitation 5–10 V; temperature-compensated per Innovatest datasheets.

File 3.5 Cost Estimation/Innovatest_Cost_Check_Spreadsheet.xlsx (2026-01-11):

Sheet: Direct_Materials
Subsystem | Total Cost [€]
Processing & Control | 5
Measurement Chain | 15
HMI | 30
Power System | 10
PCB & Passives | 14
Protective Case | 220
Miscellanous Mechanical Components | 10
Load Cells | 2844
Total | 3148

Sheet: Raw_Materials
Material | Quantity [kg] | Cost per kg [€/kg] | Cost [€]
Polycarbonate | 0.12 | 3.5 | 0.42
ABS | 0.08 | 2.5 | 0.2
5052 Aluminum | 6.6 | 4 | 26.4
EVA/PU Foam | 0.96 | 2 | 1.92
 |  | Total | 28.94

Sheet: Labor
Annual Working Hours [h] | 3780
Hourly Wage [€/h] | 20
Annual Labour Cost [€] | 75600
Labour Cost per Unit [€/unit] | 504.00

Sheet: Machine_Dep
Machine | Total Cost [€] | Annual Depreciation Rate | Depreciation Per Year [€/year] | Machine Hourly Rate [€/h] | Machine Hours per Unit [h/unit] | Machine Cost per Unit [€/unit] | Real Machine availability [minutes/year]
3D Printer | 800 | 20% | 160 | 0.0794 | 6.7 | 0.53 | 62370
4-Axis CNC Milling Machine | 70000 | 10% | 7000 | 3.4722 | 2.72 | 9.43 | 79380
3-Axis CNC Contour Machine | 50000 | 10% | 5000 | 2.4802 | 2.22 | 5.50 | 73710
3-Axis CNC Milling Machine | 9000 | 10% | 900 | 0.4464 | 1.58 | 0.707 | 79380
Extrusion Press | 100000 | 10% | 10000 | 4.9603 | 0.28 | 1.41 | 102060
Drill | 150 | 10% | 15 | 0.0074 | 0.23 | 0.00174 | 68040
Reamer | 30 | 10% | 3 | 0.0015 | 0.27 | 0.0003968 | 56700
Laser Cutter | 40000 | 10% | 4000 | 1.9841 | 0.42 | 0.827 | 79380
Welding Plant | 500 | 10% | 50 | 0.0248 | 1.28 | 0.0318 | 56700
Automated Pick-and-Place Machine | 3500 | 10% | 350 | 0.1736 | 0.18 | 0.03183 | 85050
Reflow Oven | 360 | 5% | 18 | 0.0089 | 0.34 | 0.00305 | 96390
Hand Soldering Station | 200 | 5% | 10 | 0.0050 | 0.42 | 0.00207 | 39690
Total |  |  |  |  |  | 18.47

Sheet: Utility
Machine | Power [kW] | Cost per kWh [€/kWh] | Machine Hours per Unit [h/unit] | Utility Cost per Unit [€/unit]
3D Printer | 0.15 | 0.04 | 6.70 | 0.04
4-Axis CNC Milling Machine | 8 | 2.1 | 2.72 | 45.64
3-Axis CNC Contour Machine | 2.7 | 2 | 2.22 | 11.97
3-Axis CNC Milling Machine | 1 | 2 | 1.58 | 3.17
Extrusion Press | 10 | 0.8 | 0.28 | 2.27
Drill | 0.05 | 0.02 | 0.23 | 0.00023
Reamer | 0 | 0 | 0.27 | 0
Laser Cutter | 4.5 | 1.17 | 0.42 | 2.19
Welding Plant | 2.5 | 0.65 | 1.28 | 2.09
Automated Pick-and-Place Machine | 0.2 | 0.05 | 0.18 | 0.00183
Reflow Oven | 1.2 | 0.31 | 0.34 | 0.13
Hand Soldering Station | 0.07 | 0.02 | 0.42 | 0.00058
Total |  |  |  | 67.49

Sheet: Rent
Rent per square meter [€/m^2] | 7
Additional Cost percent [-] | 15% | 1260
Size [m^2] | 100
Total Annual Rent [€/year] | 9660
Rent per Unit [€/unit] | 64.40

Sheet: Summary
Item | € per Unit
Direct Material Costs [€/unit] | 3148
Raw Material Costs [€/unit] | 28.94
Material Overhead [-] | 5% | 158.85
Total Material Costs [€/unit] | 3335.79
Labor Costs [€/unit] | 504.00
Machine Costs [€/unit] | 18.47
Utility Costs [€/unit] | 67.49
Rent [€/unit] | 64.40
Manufacturing Costs [€/unit] | 654.36
Production Costs [€/unit] | 3990.15
Admin Overhead | 8% | 319.21
Marketing & Sales Overhead | 15% | 598.52
COGS [€/unit] | 4907.89
Profit Margin | 30% | 1472.37
Cash Selling Price | 6380.25
Distributor Commission | 10% | 638.03
Final Offer Price | 7018.28

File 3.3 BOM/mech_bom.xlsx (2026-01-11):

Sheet: BOM_word
Position Number | Part Name | Material | Qty | Standard[1] | Verified (from SW) | Verified (from Ahmad)
2 | PCB Mount | General Purpose Polycarbonate | 1 | ISO 21305-1:2019 | TRUE | TRUE
3 | Battery Cradle | Heat resistant ABS | 1 | ISO 2580-1 ABS | TRUE | TRUE
4 | Panel Frame | 5052 Aluminium | 1 | ISO: Al-Mg2,5 | TRUE | TRUE
5 | Load Cell Compartment | Medium Density EVA Foam | 1 | ISO 7214 1998 | TRUE | TRUE
6 | Aluminium Box Foam | Medium Density EVA Foam | 1 | ISO 7214 1998 | TRUE | TRUE
7 | Electronics Basin | 5052 Aluminium | 1 | ISO: Al-Mg2,5 | TRUE | TRUE
8 | Aluminium Frame | 5052 Aluminium | 1 | ISO: Al-Mg2,5 | TRUE | TRUE
9 | Panel | 5052 Aluminium | 1 | ISO: Al-Mg2,5 | TRUE | TRUE
10 | Cable Tray | 5052 Aluminium | 1 | ISO: Al-Mg2,5 | TRUE | TRUE
11 | Top Foam | Medium Density EVA Foam | 1 | ISO 7214 1998 | TRUE | TRUE
12 | Pelican Case | Polypropylene | 1 | - | TRUE | TRUE
27 | M4 x 0.7 x 12 Button Head Screws | stainless steel A2 | 12 | ISO 7380 | TRUE | TRUE
28 | M3 x 0.5 x 10 Button Head Screws | stainless steel A2 | 4 | ISO 7380 | TRUE | TRUE
29 | M3 x 0.5 x 8 Button Head Screws | stainless steel A2 | 12 | ISO 7380 | TRUE | TRUE
30 | M3 x 0.5 x 6 Button Head Screws | stainless steel A2 | 2 | ISO 7380 | TRUE | TRUE
31 | M2 x 0.4 x 16 Slotted Pan Head Screw | stainless steel A2 | 4 | ISO 1580 | TRUE | TRUE
32 | ST2.9 x 9.5 Tapping Screws | stainless steel A2 | 4 | ISO 14585 | TRUE | TRUE
33 | M4 x 0.7 x 9.2 Rivet Nuts | stainless steel A2 | 12 | DIN 7337 | TRUE | TRUE
34 | M3 x 0.5 Hex Nuts | stainless steel A2 | 16 | ISO 4032 | TRUE | TRUE
35 | M2 x 0.4 Hex Nuts | stainless steel A2 | 4 | ISO 4035 | TRUE | TRUE
36 | M4 Washers | stainless steel A2 | 12 | ISO 7092 | TRUE | TRUE
37 | M3 Washers | stainless steel A2 | 18 | ISO 7092 | TRUE | TRUE
38 | O-ring | Silicone Rubber | 1 | ISO 3601 | TRUE | TRUE
39 | Seal for Screen Bezel | PVC Foam Tape | 1 | ISO 29864 | TRUE | TRUE
40 | Aluminium Frame Gasket | PVC Foam Tape | 1 | ISO 29864 | TRUE | TRUE
41 | USB C Gasket | Built into bought product | 1 | ISO 29864 | TRUE | TRUE
42 | M12 Gasket | PVC Foam Tape | 1 | ISO 29864 | TRUE | TRUE
43 | Velcro Roll | Velcro | 1 | - | TRUE | TRUE
[1] For custom “Make” parts, the ISO standard refers to the material while for “Buy” parts it is the design of the machine element itself
1 | Printed Circuit Board | Würth Elektronik | 1
13 | M12 Load Cell Cable | Binder | 1
14 | TouchScreen/SPI Touch Controller | EastRising | 1
15 | Push Buttons | Metzler | 2
16 | M12 5-pin | Phoenix Contact | 1
17 | USB A | Stewart Connector | 1
18 | USB C | Stewart Connector | 1
19 | Bi-colour LED Light Pipe | Bivar | 1
20 | Battery | YDL | 1
21 | 150 gf Load Cell | Innovatest | 1
22 | 2 kgf Load Cell | Innovatest | 1
23 | 20 kgf Load Cell | Innovatest | 1
24 | 45 kgf Load Cell | Innovatest | 1
25 | 250 kgf Load Cell | Innovatest | 1
26 | 3000 kgf Load Cell | Innovatest | 1

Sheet: BOM_template
1 | 1 | Printed Circuit Board |  | 33946-2015.02 | 00 | FR-4 and Copper
2 | 1 | PCB Mount | ISO 21305-1:2019 | 33946-2015.02 | 00 | General Purpose Polycarbonate
3 | 1 | Battery Cradle | ISO 2580-1 ABS | 33946-2015.02 | 00 | Heat resistant ABS
4 | 1 | Panel Frame | ISO: Al-Mg2,5 | 33946-2015.02 | 00 | 5052 Aluminium
5 | 1 | Load Cell Compartment | ISO 7214 1998 | 33946-2015.02 | 00 | Medium Density EVA Foam
6 | 1 | Aluminium Box Foam | ISO 7214 1998 | 33946-2015.02 | 00 | Medium Density EVA Foam
7 | 1 | Electronics Basin | ISO: Al-Mg2,5 | 33946-2015.02 | 00 | 5052 Aluminium
8 | 1 | Aluminium Frame | ISO: Al-Mg2,5 | 33946-2015.02 | 00 | 5052 Aluminium
9 | 1 | Panel | ISO: Al-Mg2,5 | 33946-2015.02 | 00 | 5052 Aluminium
10 | 1 | Cable Tray | ISO: Al-Mg2,5 | 33946-2015.02 | 00 | 5052 Aluminium
11 | 1 | Top Foam | ISO 7214 1998 | 33946-2015.02 | 00 | Medium Density EVA Foam
12 | 1 | Pelican Case | - | 33946-2015.02 | 00 | Polypropylene
13 | 1 | M12 Load Cell Cable | - | 33946-2015.02 | 00 | -
14 | 1 | TouchScreen/SPI Touch Controller | - | 33946-2015.02 | 00 | -
15 | 2 | Push Buttons | - | 33946-2015.02 | 00 | -
16 | 1 | M12 5-pin | - | 33946-2015.02 | 00 | -
17 | 1 | USB A | - | 33946-2015.02 | 00 | -
18 | 1 | USB C | - | 33946-2015.02 | 00 | -
19 | 1 | Bi-colour LED Light Pipe | - | 33946-2015.02 | 00 | -
20 | 1 | Battery | - | 33946-2015.02 | 00 | -
21 | 1 | 150 gf Load Cell | - | 33946-2015.02 | 00 | -
22 | 1 | 2 kgf Load Cell | - | 33946-2015.02 | 00 | -
23 | 1 | 20 kgf Load Cell | - | 33946-2015.02 | 00 | -
24 | 1 | 45 kgf Load Cell | - | 33946-2015.02 | 00 | -
25 | 1 | 250 kgf Load Cell | - | 33946-2015.02 | 00 | -
26 | 1 | 3000 kgf Load Cell | - | 33946-2015.02 | 00 | -
27 | 12 | M4 x 0.7 x 12 Button Head Screws | ISO 7380 | 33946-2015.02 | 00 | stainless steel A2
28 | 4 | M3 x 0.5 x 10 Button Head Screws | ISO 7380 | 33946-2015.02 | 00 | stainless steel A2
29 | 12 | M3 x 0.5 x 8 Button Head Screws | ISO 7380 | 33946-2015.02 | 00 | stainless steel A2
30 | 2 | M3 x 0.5 x 6 Button Head Screws | ISO 7380 | 33946-2015.02 | 00 | stainless steel A2
31 | 4 | M2 x 0.4 x 16 Slotted Pan Head Screw | ISO 1580 | 33946-2015.02 | 00 | stainless steel A2
32 | 4 | ST2.9 x 9.5 Tapping Screws | ISO 14585 | 33946-2015.02 | 00 | stainless steel A2
33 | 12 | M4 x 0.7 x 9.2 Rivet Nuts | DIN 7337 | 33946-2015.02 | 00 | stainless steel A2
34 | 16 | M3 x 0.5 Hex Nuts | ISO 4032 | 33946-2015.02 | 00 | stainless steel A2
35 | 4 | M2 x 0.4 Hex Nuts | ISO 4035 | 33946-2015.02 | 00 | stainless steel A2
36 | 12 | M4 Washers | ISO 7092 | 33946-2015.02 | 00 | stainless steel A2
37 | 18 | M3 Washers | ISO 7092 | 33946-2015.02 | 00 | stainless steel A2
38 | 1 | O-ring | ISO 3601 | 33946-2015.02 | 00 | Silicone Rubber
39 | 1 | Seal for Screen Bezel | ISO 29864 | 33946-2015.02 | 00 | PVC Foam Tape
40 | 1 | Aluminium Frame Gasket | ISO 29864 | 33946-2015.02 | 00 | PVC Foam Tape
41 | 1 | USB C Gasket | ISO 29864 | 33946-2015.02 | 00 | Built into bought product
42 | 1 | M12 Gasket | ISO 29864 | 33946-2015.02 | 00 | PVC Foam Tape
43 | 1 | Velcro Roll | - | 33946-2015.02 | 00 | Velcro
item | qty. | description | specification | drawing no. | rev. | material

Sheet: BOM_SW
ITEM NO. | PART NUMBER | DESCRIPTION | QTY. | Added
1 | 1500bot- rev G |  | 1 | TRUE
2 | 1501-931T-CLR |  | 1 | TRUE
3 | Aluminum Box Pt 1 |  | 1 | TRUE
4 | Aluminum Box Pt 2 |  | 1 | TRUE
5 | gasket |  | 1 | TRUE
6 | Washer ISO 7092 - 3 |  | 18 | TRUE
7 | ISO 7380 - M3 x 8 - 8N |  | 12 | TRUE
8 | ISO - 4032 - M3 - W - N |  | 16 | TRUE
9 | panel |  | 1 | TRUE
10 | 1500-PF |  | 1 | TRUE
11 | O-Ring |  | 1 | TRUE
12 | Compartment for Cables n other stuff idk what to call it |  | 1 | TRUE
13 | Seal For Screen Bezel |  | 1 | TRUE
14 | Touch Screen |  | 1 | TRUE
15 | PushButton_P19-TF- POWER-RGB |  | 2 | TRUE
16 | SS-52200-001 |  | 1 | TRUE | USB A
17 | PLTR5-8MM-PR1 |  | 1 | TRUE | LED
18 | ISO 7380 - M3 x 6 - 6N |  | 2 | TRUE
19 | Battery Cradle |  | 1 | TRUE
20 | Lipo Battery 7000 mAh |  | 1 | TRUE
21 | Velcro Strap |  | 1 | TRUE
22 | ISO 7380 - M3 x 10 - 10N |  | 4 | TRUE | button head screws
23 | Load Cell Compartment |  | 1 | TRUE
24 | LC-40-0003 - 3D CAD load cell pancake 3000 kgf (F3000K) |  | 1 | TRUE
25 | LC-40-0005 - 3D CAD load cell pancake 250 kgf (F250K) |  | 1 | TRUE
26 | LC-40-0007 - 3D CAD load cell donut B 20 kgf (E20K) |  | 1 | TRUE
27 | LC-40-4502 - 3D CAD load cell donut A 45 kgf (D45K) |  | 1 | TRUE
28 | SA-01-0041 - LC-40- 0006 - 3D CAD load cell flat 150 gf (A151) |  | 1 | TRUE
29 | SA-01-0050 - LC-40- 0202 - 3D CAD load cell flat 2 kgf (C202) |  | 1 | TRUE
30 | Washer ISO 7092 - 4 |  | 12 | TRUE
31 | ISO 7380 - M4 x 12 - 12N |  | 12 | TRUE
32 | M4 x 10 Rivet |  | 12 | TRUE
33 | Foam Around Aluminum Box |  | 1 | TRUE
34 | Board Mount |  | 1 | TRUE
35 | Inoovatest_PCB_Fo otprints |  | 1 | TRUE
36 | ISO 1580 - M2 x 16 - 16N |  | 4 | TRUE
37 | ISO - 4035 - M2 - N |  | 4 | TRUE
38 | Tapping Screw ISO 14585 - ST2.9 x 9.5- C-N |  | 4 | TRUE
39 | SS-52400- 012_1_ASM-0.stp | NOT SPECIFIED | 1 | TRUE
40 | SS-52400- 012_GASKET.stp | NOT SPECIFIED | 1 | TRUE
41 | Gasket For M12 |  | 1 | TRUE
42 | Hinge Rod |  | 2 | TRUE
43 | Case Handle |  | 1 | TRUE
44 | Handle Rod |  | 2 | TRUE
45 | foam-for-top |  | 1 | TRUE
46 | 1697098 |  | 1 | TRUE

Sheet: BOM_elec
Reference | Part | Brand | Quantity | Cost per unit | Cost
BT1 | Battery Terminal (XT90PW) | AMASS | 1
C1, C23 | Voltage Blocking Capacitor (ECA-1HM101B) | Panasonic | 2
C2, C4, C5, C6, C8, C10, C13, C15, C19, C20, C27, C33, C40 | Decoupling Capacitor (GRT21BR71H104KE01L) | Murata | 13
C3 | Filter Capacitor (GRM21BR71C105KA01K) | Murata | 1
C7, C9, C11, C12, C24, C25, C26, C28, C34, C35, C37, C41 | Decoupling Capacitor (GCJ31CR71C106KA15K) | Murata | 12
C14 | Filter Capacitor (GCM21BR71C335KA73L) | Murata | 1
C16 | Filter Capacitor (GRM21BR71C475KE51L) | Murata | 1
C17 | Filter Capacitor (GRM21BR71C334JA01L) | Murata | 1
C18 | Filter Capacitor (GRM219R71C474JA01D) | Murata | 1
C21 | Capacitor (GCQ0335C1H100JB01D) | Murata | 1
C22 | Capacitor (GRJ21AR72E102KWJ1D) | Murata | 1
C29 | Capacitor (GRM21AR7LU332KW01D) | Murata | 1
C30, C31, C32, C36, C39 | Capacitor (GRM31CZ71C226ME15K) | Murata | 5
C38 | Capacitor (GRT21BR71C225KE01L) | Murata | 1
D1 | ESD Diode | Vishay | 1
 | (SMF5V0A)
19 | Bi-colour LED Light Pipe | Bivar | 1
(D2 in 10.3.1 Schematic) | (PLTR5-8MM-PR1)
D3, D4 | Schottky Diode | STMicro-electronics | 2
 | (STPS340S)
IC1 | Charging Controller (MCP73223) | Microchip | 1
IC2 | Voltage Reference (MAX6126) | Maxim Integrated | 1
L1, L3, L4 | Inductor | Delevan | 3
 | (8532R-09K)
L2 | Inductor | Bourns | 1
 | (RLB0913-2R2K)
Q1, Q2, Q5 | P-Channel MOSFET | Alpha & Omega | 3
 | (AO3401A)
Q3, Q4, Q6 | N-Channel MOSFET | Alpha & Omega | 3
 | (AO3400A)
R1, R2 | Resistor (TNPW08055K10FETA) | Vishay | 2
R3 | Resistor (ROX050500KFKLB) | Vishay | 1
R4 | Resistor | Xicon | 1
 | (271-24.3K-AP-RC)
R5 | Resistor | YAGEO | 1
 | (RSF200JR-52-200K)
R6, R9, R10 | Precision Resistor | Panasonic | 3
 | (ERA-3AEB103V)
R12, R13, R15, R20, R21, R24, R25, R26, R30, R31, R34, R35 | Resistor | YAGEO | 11
 | (RSF50SJT-52-10K)
R7 | Precision Resistor | Panasonic | 1
 | (ERA-3AEB101V)
R8 | Precision Resistor | Panasonic | 1
 | (ERA-3ARB472V)
R11 | Precision Resistor | Panasonic | 1
 | (ERA-3AEB4991V)
R14 | Resistor (RSPF12JT1K20) | SEI Stackpole | 1
R16 | Resistor | YAGEO | 1
 | (RSF100JT-73-1K)
R17, R22 | Resistor (RNF14BBE100K) | SEI Stackpole | 2
R18 | Resistor | YAGEO | 1
 | (RSF100JB-73-1M)
R19 | Resistor | YAGEO | 1
 | (MFR-25FBF52-71K5)
R23 | Resistor (PTF6531K250BZWF) | Vishay | 1
R27 | Resistor | YAGEO | 1
 | (MFR-25FBF52-301K)
R28 | Resistor (PTF6540K000FZBF) | Vishay | 1
R29 | Resistor | YAGEO | 1
 | (MFR-25FBF52-4K87)
R32 | Resistor (MF1/4DC1742F) | KOA Speer | 1
R33 | Resistor | YAGEO | 1
 | (MFR-25FRF52-127K)
R36 | Resistor | YAGEO | 1
 | (RSF-50JT-52-20K)
R37 | Precision Resistor | Panasonic | 6
 | (ERA-3AEB104V)
R | Precision Resistor | Panasonic | 6
 | (ERA-3AEBxxxV)
U1 | Instrumentation Amplifier (AD8421) | Analog Devices | 1
U2 | Operational Amplifier (OPA188) | Texas Instruments | 1
U3 | Delta-Sigma Analogue to Digital Converter (ADS127L21) | Texas Instruments | 1
U4 | Digital Potentiometer (MCP41U83) | Microchip | 1
U5 | Optocoupler (PS9117A) | Renesas | 1
U6 | 10V Voltage Regulator (TPS61170) | Texas Instruments | 1
U7 | 3.3V Voltage Regulator | Texas Instruments | 1
 | (TPS62130)
U8 | 5V Voltage Regulator | Texas Instruments | 1
 | (TPS61099)
U9 | 5.5V Voltage Regulator | Texas Instruments | 1
 | (TPS61089)
U10 | Non-volatile Memory (W25Q128JVS) | Winbond | 1
U11 | Microcontroller | Espress-if | 1
 | (ESP32-P4)
1 | Printed Circuit Board | Würth Elektronik | 1
13 | M12 Load Cell Cable (77 2529 0000 50705-0200) | Binder | 1
14 | TouchScreen/SPI Touch Controller | EastRising | 1
(U12 in 10.3.1 Schematic) | (ER-TFT101-1)
15 | Push Buttons (P19TFRGBPOWER) | Metzler | 2
(SW1, SW2 in 10.3.1 Schematic)
16 | M12 5-pin | Phoenix Contact | 1
(J1 in 10.3.1 Schematic) | (ABQEHI)
17 | USB A | Stewart Connector | 1
(J2 in 10.3.1 Schematic) | (SS-52200-001)
18 | USB C | Stewart Connector | 1
(J3 in 10.3.1 Schematic) | (SS-52400-012)
20 | Battery | YDL | 1
 | (YDL866898)
21 | 150 gf Load Cell | Innovatest | 1
 | (A151)
22 | 2 kgf Load Cell | Innovatest | 1
 | (C202)
23 | 20 kgf Load Cell | Innovatest | 1
 | (E20K)
24 | 45 kgf Load Cell | Innovatest | 1
 | (D45K)
25 | 250 kgf Load Cell | Innovatest | 1
 | (F250K)
26 | 3000 kgf Load Cell | Innovatest | 1
 | (F3000K)
Shouldn’t there be 5 of these?

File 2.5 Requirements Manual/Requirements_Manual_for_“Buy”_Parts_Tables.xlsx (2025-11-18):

 | ELECTRICAL 'BUY' PARTS |  |  |  |  |  |  | MECHANICAL 'BUY' PARTS
#VALUE!
 | # | Component | Spec-Match Status | Preliminary BOM Price (€) | Realistic Price Range (€) | Upgrade Needed? | Reason | # | Column1 | Document Price (€) | Realistic Price Range (€) | Upgrade Needed? | Reason
 | 1 | Microcontroller (MCU) | OK | 4 | 2.5–3.5 | No | BOM price slightly high but acceptable. | 1 | Protective Carrying Case (IP67) | 200 | 70–80 | YES (price too high) | Professional IP67 polypropylene cases (B&W, Peli, Explorer) cost 70–90 €. 200 € is more than 2× market price unless it includes custom foam (which is listed separately).
 | 2 | Load Cell Connector | OK | 40 | 20–40 | No | Upper end but realistic for shielded multi-core cable. | 2 | Foam (CNC-cut EVA/PU insert) | 50 | 40–100 | NO | 50 € is realistic for a single custom laser/CNC insert. Price aligns with typical prototype foam machining.
 | 3 | Load Cell Interface Port | OK | 5 | 5–12 | No | 5 € is low but still possible for basic M12 panel connector. | 3 | 1-Panel Frame (Front Panel) | 30 | 20–40 | NO | Document price matches CNC-cut 2–3 mm anodised aluminium front plates.
 | 4 | Noise and Low-pass Filter | OK | 2 | 2–5 | No | Passive RC parts are very cheap; 2 € is realistic. | 4 | Internal Aluminium Frame | 150 | 15–30 | YES (price far too high) | Standard 20×20 aluminium extrusion profiles + brackets for a small enclosure cost 15–30 €. 150 € is 5–10× above realistic.
 | 5 | Amplifier | ❌ Not OK | 4 | 7–12 | Yes | Spec-compliant instrumentation amplifiers cost >7 €. | 5 | Mechanical Misc (Screws, O-rings, Brackets) | 50 | 20–30 | YES (price too high) | Stainless M3/M4 screw sets + O-ring kit + 2–4 brackets normally cost 20–30 €. 50 € is nearly double typical BOM cost.
 | 6 | ADC Module | OK | 10 | 6–13 | No | Typical 24-bit ADC (ADS1232) module price.
 | 7 | Cell Excitation Regulator | OK | 8 | 5–10 | No | Matches buck + LDO regulation for 5/10 V excitation.
 | 8 | Touchscreen Display | ❌ Not OK | 100 | 120–150 | Yes | Spec-compliant 10.1″ resistive TFT is ≥120 €.
 | 9 | Latching Push Button | ❌ Not OK | 40 | 12–24 | Yes | IP65 metal latching buttons ~6–12 € each.
 | 10 | Internal Memory Module | ⚠ Slightly low | 3 | 4–6 | Yes | SPI-NOR Flash ≥8 MB costs at least 4 €.
 | 11 | USB-A Port | OK | 1 | 1–2.5 | No | 1 € is realistic for panel-mount USB-A.
 | 12 | Power Regulator | ⚠ Slightly low | 4 | 5–10 | Yes | 5 V / 3.3 V low-ripple regulators cost ≥5 €.
 | 13 | USB-C Port | OK | 2 | 1.5–3 | No | 2 € fits typical USB-C power-only receptacles.
 | 14 | Battery Charging Circuit | OK | 5 | 5–10 | No | Li-ion CC/CV charger modules commonly 5–10 €.
 | 15 | Battery | OK | (fill) | 8–20 | No | 5000 mAh Li-ion packs generally 8–20 €.
 | 16 | Misc | OK | (fill) | 10–20 | No | Mixed passives & headers cost around 10–20 €.

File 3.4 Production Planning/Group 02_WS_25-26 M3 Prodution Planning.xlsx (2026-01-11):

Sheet: takt-time
Parameter | Year 1 | Year 2 | Year 3
Target Annual Production ($U_{year}^{total}$) | 150 | 150 | 200
Working Days per Year ($D_{year}$) | 252 | 252 | 252
Shifts per Day ($N_{shifts}$) | 1 | 1 | 1
Time per Shift ($t_{shift}$) [s] | 27000 | 27000 | 27000
Available Time per Year ($t_{w}$) [s] | 6804000 | 6804000 | 6804000
Takt Time ($T$) [s] | 45360 | 45360 | 34020
Takt Time ($T$) [min] | 756 | 756 | 567
Takt Time ($T$) [hr] | 12.6 | 12.6 | 9.45

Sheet: machine-efficiency
Machine | OEE | Ideal Machine Availability [minutes/day] | Real Machine availability [minutes/day] | Real Machine availability [minutes/year]
3D Printer | 55% | 450 | 247.5 | 62370
4-Axis CNC Milling Machine | 70% | 450 | 315 | 79380
3-Axis CNC Contour Machine | 65% | 450 | 292.5 | 73710
3-Axis CNC Milling Machine | 70% | 450 | 315 | 79380
Extrusion Press | 90% | 450 | 405 | 102060
Drill | 60% | 450 | 270 | 68040
Reamer | 50% | 450 | 225 | 56700
Laser Cutter | 70% | 450 | 315 | 79380
Welding Plant | 50% | 450 | 225 | 56700
Automated Pick-and-Place Machine | 75% | 450 | 337.5 | 85050
Reflow Oven | 85% | 450 | 382.5 | 96390
Hand Soldering Station | 35% | 450 | 157.5 | 39690

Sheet: production-time
Position Number | Part | Process(s) | Processing Time [min/unit] | Setup Time [min/unit] | Production Time Per Unit [min/unit] | Production Volume [units/year] | Total Production Time [min/year]
1 | Printed Circuit Board | Etching, Screen printing | 102 | 15 | 117 | 150 | 17550
2 | PCB Mount | 3D Printing | 193 | 2 | 195 | 150 | 29250
3 | Battery Cradle | 3D Printing | 202 | 5 | 207 | 150 | 31050
4 | Panel Frame | 4-axis CNC Milling | 30 | 16 | 46 | 150 | 6900
5 | Load Cell Compartment | 3-axis CNC Contour | 35 | 10 | 45 | 150 | 6750
6 | Aluminium Box Foam | 3-axis CNC Contour | 60 | 15 | 75 | 150 | 11250
7 | Electronics Basin | Backward Extrusion and 4-axis CNC Milling | 74 | 60 | 134 | 150 | 20100
8 | Aluminium Frame | Fiber Glass Laser cutting and Manual Welding | 40 | 30 | 70 | 150 | 10500
9 | Panel | 3-axis CNC Milling | 40 | 25 | 65 | 150 | 9750
10 | Cable Tray | 3-axis CNC Milling | 20 | 10 | 30 | 150 | 4500
11 | Top Foam | 3-axis CNC Contour | 8 | 5 | 13 | 150 | 1950
12 | Lower Pelican Case | Manual Drilling and Reaming | 10 | 10 | 20 | 150 | 3000
13 | M12 Load Cell Cable | Soldering | 10 | 5 | 15 | 150 | 2250
 |  |  |  |  | 1032

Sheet: machine-allocation
Machine | Required Production Time [min/year] | Machine Availability [min/year] | No. of Machines | No. of Machines (estimate)
3D Printer | 60300 | 62370 | 1 | 0.9668109668
4-Axis CNC Milling Machine | 24450 | 79380 | 1 | 0.3080120937
3-Axis CNC Contour Machine | 19950 | 73710 | 1 | 0.2706552707
3-Axis CNC Milling Machine | 14250 | 79380 | 1 | 0.1795162509
Extrusion Press | 2550 | 102060 | 1 | 0.02498530276
Drill | 2100 | 68040 | 1 | 0.03086419753
Reamer | 2400 | 56700 | 1 | 0.04232804233
Laser Cutter | 3750 | 79380 | 1 | 0.04724111867
Welding Plant | 11550 | 56700 | 1 | 0.2037037037
Automated Pick-and-Place Machine | 1650 | 85050 | 1 | 0.01940035273
Reflow Oven | 3075 | 96390 | 1 | 0.03190164955
Hand Soldering Station | 3750 | 39690 | 1 | 0.09448223734

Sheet: workforce
PRODUCTION
Machine | No. of Machines | Required Production Time [h/year] | Required Working Hours [h/day] | Required Shifts [shifts/day]
3D Printer | 1 | 1005.0 | 6.7 | 0.893
4-Axis CNC Milling Machine | 1 | 407.5 | 2.7 | 0.362
3-Axis CNC Contour Machine | 1 | 332.5 | 2.2 | 0.296
3-Axis CNC Milling Machine | 1 | 237.5 | 1.6 | 0.211
Extrusion Press | 1 | 42.5 | 0.3 | 0.038
Drill | 1 | 35.0 | 0.2 | 0.031
Reamer | 1 | 40.0 | 0.3 | 0.036
Laser Cutter | 1 | 62.5 | 0.4 | 0.056
Welding Plant | 1 | 192.5 | 1.3 | 0.171
Hand Soldering Station | 1 | 27.5 | 0.2 | 0.024
 |  |  | 15.9 | 2.118
 |  |  | 9.2 | 1.2
ASSEMBLY
Assembly Station | Required Assembly Time [h/year] | Required Working Hours [h/day] | Required Shifts [shifts/day] |  | Required Assembly Time [min/unit]
Line 1 – Basin Assembly | 145 | 0.58 | 0.0767 |  | 58
Line 2 – Top Panel Assembly | 45 | 0.18 | 0.0238 |  | 18
Line 3 – Electronics interior assembly | 47.5 | 0.19 | 0.0251 |  | 19
Line 4 – Panel frame assembly | 7.5 | 0.03 | 0.0040 |  | 3
Line 5 – Pelican case assembly | 17.5 | 0.07 | 0.0093 |  | 7
Line 6 – Final assembly | 5 | 0.02 | 0.0026 |  | 2
 |  | 1.06 | 0.1415343915
WORKFORCE
Hrs | 10.245 | 11 | 2581.7
Shifts | 1.37 | 2.000 | 3780 |  | Shifts including 3D printing | 2.259

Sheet: production-time-calc
PRODUCTION
Position Number | Part | Process Steps | Process Step Time [min] | Processing Time Per Unit [min/unit] | Setup Time Per Unit [min/unit] | Total Time [min/unit] | Notes
1 | Printed Circuit Board | Cutting | 2.00 | 102.00 | 15.00 | 117.00
 |  | Treatment | 10.00
 |  | Etching | 40.00
 |  | Drilling | 10.00
 |  | Surface Finish | 20.00
 |  | Screen Printing | 20.00
 |  | Transfering between stations | 15.00
2 | PCB Mount | 3D Printing | 193.00 | 193.00 | 2.00 | 195.00 | 0.2mm layer, quality, 70% infill w/ supportts
 |  | Support removal | 2.00
3 | Battery Cradle | 3D Printing | 202.00 | 202.00 | 5.00 | 207.00 | 0.2mm layer, quality, 30% infill w/ supportts
 |  | Support removal | 5.00
4 | Panel Frame | Secure workpiece | 5.00 | 30.00 | 16.00 | 46.00
 |  | Center cut out | 6.00
 |  | Remove center piece | 3.00
 |  | Feature milling | 18.00
 |  | Rotate workpiece | 4.00
 |  | Milling holes | 3.00
 |  | Rotate workpiece | 4.00
 |  | Milling holes | 3.00
5 | Load Cell Compartment | 3-axis CNC Contour |  | 35 | 10 | 45.00
6 | Aluminium Box Foam | 3-axis CNC Contour |  | 60 | 15 | 75.00
7 | Electronics Basin | Secure workpiece | 10.00 | 74.00 | 60.00 | 134.00
 |  | Extrusion Process | 2.00
 |  | Remove workpiece | 5.00
 |  | Transfer piece to CNC Mill | 25.00
 |  | Milling groves (x4) | 40.00
 |  | Rotating (x4) | 20.00
 |  | Milling hole | 2.00
 |  | Finishing (x4) w/ grinder | 30.00
8 | Aluminium Frame | Loading laser cutter | 10.00 | 40.00 | 30.00 | 70.00
 |  | Laser cutting | 10.00
 |  | Collect workpieces | 5.00
 |  | Setup and secure workpieces | 15.00
 |  | Weld work pieces | 30.00
9 | Panel | 3-axis CNC Milling |  | 40 | 25 | 65.00
10 | Cable Tray | 3-axis CNC Milling |  | 20 | 10 | 30.00
11 | Top Foam | 3-axis CNC Contour |  | 8 | 5 | 13.00
12 | Lower Pelican Case | Secure workpiece | 10.00 | 10.00 | 10.00 | 20.00
 |  | Drilling | 4.00
 |  | Reaming | 6.00
13 | M12 Load Cell Cable | Soldering |  | 10 | 5 | 15.00
MACHINES
 |  | Required prodution Time per unit [min/unit] | Required prodution Time per year [min/year] | Required prodution Time per unit [hr/unit] | Required prodution Time per year [hr/year]
 | 3D Printer | 402.00 | 60300.00 | 6.7 | 1005
 | 4-Axis CNC Milling Machine | 163.00 | 24450.00 | 2.716666667 | 407.5
 | 3-Axis CNC Contour Machine | 133.00 | 19950.00 | 2.216666667 | 332.5
 | 3-Axis CNC Milling Machine | 95.00 | 14250.00 | 1.583333333 | 237.5
 | Extrusion Press | 17.00 | 2550.00 | 0.2833333333 | 42.5
 | Drill | 14.00 | 2100.00 | 0.2333333333 | 35
 | Reamer | 16.00 | 2400.00 | 0.2666666667 | 40
 | Laser Cutter | 25.00 | 3750.00 | 0.4166666667 | 62.5
 | Welding Plant | 77.00 | 11550.00 | 1.283333333 | 192.5
 | Automated Pick-and-Place Machine | 11.00 | 1650.00 | 0.1833333333 | 27.5
 | Reflow Oven | 20.50 | 3075.00 | 0.3416666667 | 51.25
 | Hand Soldering Station | 25.00 | 3750.00 | 0.4166666667 | 62.5
 |  |  |  | 16.64166667
ASSEMBLY
Position Number | Part | Process Steps | Process Step Time [min] | Total Time [min/unit]
A1 | Printed Circuit Board | Secure PCB in stencil | 2.00 | 50.00
 |  | Apply solder paste | 5.00
 |  | Remove from stencil | 1.50
 |  | Secure PCB into pnp | 2.50
 |  | PnP places all components | 7.00
 |  | Remove from pnp | 1.50
 |  | Secure in Oven | 1.00
 |  | Reflow in Oven | 15.00
 |  | Remove from Oven (+cooling) | 4.50
 |  | Hand solder THT components | 10.00
A4 | Top Panel and Tray | Secure workpiece | 8.00 | 14.00
 |  | Weld | 6.00
A11 | Basin + Panel | Secure workpiece | 8.00 | 18.00
 |  | Weld | 10.00

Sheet: assembly-stations
Assembly Station | Sub assembly station | Parts assembly | Assembly Process | No. of Machines | Total Time (mins) | Assembly Lines
Line 1 – Basin Assembly | Line 1.1 – PCB Assembly (A1) | Part 1 and all electrical components (Table 27, except USB C and M12 port) | Place solder paste using stencil | 1 | 50 | Y1 | 0.1415343915
 |  |  | Place all components (Automated pick and place machine) |  |  | Y2 | 0.1415343915
 |  |  | Solder (Reflow oven) |  |  | Y3 | 0.188712522
 | Line 1.2 – PCB mount assembly (A3) | 1, 2, 16 and 22 | Screw PCB into Mount | - | 1
 | Line 1.3 – Battery Cradle Assembly (A2) | 3 and 25 | Strap Velcro onto cradle | - | 1
 | Line 1.4 – | 2, 7, 17 and 21 | Screw the battery cradle in | - | 1
 | Battery cradle into basin (A6)
 | Line 1.5 – M12 port into basin (A8) | 7, 13 and M12 gasket | Insert M12 port into the basin | - | 1
 | Line 1.6 – PCB Mount into basin (A7) | 2, 7 and 27 | Tape the PCB mount onto the wall | - | 2
 | Line 1.7 – Frame and gasket onto basin (A9 & A10) | 7, 8, Battery, 17 , 21, 24 and 26 | Place in the battery, then place gasket and screw frame on to the basin | - | 2
Line 2 – Top Panel Assembly | Line 2.1 – Top Panel welding (A4) | 9 and 10 | Weld cable tray onto top panel | 1 | 14
 | Line 2.2 – Buttons and ports insertion | SW1, SW2, J2, D2, 9, 18 and 24 | Screw the buttons, LEDs and USB A port into the top panel | - | 4
Line 3 – Electronics interior assembly | Line 3.1 – Top panel and basin assembly (A11) | 7 and 9 | Weld top panel and basin together | 1 | 18
 | Line 3.2 – Screen insertion (A12) | 7, EDPM Foam tape and U12 | Insert screen and tape for sealing | - | 1
Line 4 – Panel frame assembly | (A14) | 4 and 20 | Insert rivets into panel frame | - | 3
Line 5 – Pelican case assembly | Line 5.1 – USB C port insertion (A13) | J3 and 12 | Insert USB – C port | - | 1
 | Line 5.2 – screw in panel frame (A15 & A16) | 4, 5, 6, 11, 12 and 19 and glue | Insert foam into case, then screw in panel frame | - | 4
 | Line 5.3 – electronics insertion (A17) | 7, 12 and O-ring | Screw in electronics with O-ring | - | 2
Line 6 – Final assembly | A18 | 12 and load cells and cables | Keep the load cells and cables in and close the box | - | 2
 |  |  |  |  | 107

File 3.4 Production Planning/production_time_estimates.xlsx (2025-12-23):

Position Number | Part | Process(s) | Processing Time [min/unit] | Setup Time [min/unit] | Production Time Per Unit [min/unit] | Production Volume [units/year] | Total Production Time [min/year]
1 | Printed Circuit Board | Etching, Screen printing | 102 | 20 | 122 | 150 | 18300
2 | PCB Mount | 3D Printing | 60 | 15 | 75 | 150 | 11250
3 | Battery Cradle | 3D Printing | 45 | 10 | 55 | 150 | 8250
4 | Panel Frame | 4-axis CNC Milling | 30 | 20 | 50 | 150 | 7500
5 | Load Cell Compartment | 3-axis CNC Contour | 25 | 15 | 40 | 150 | 6000
6 | Aluminium Box Foam | 3-axis CNC Contour | 10 | 5 | 15 | 150 | 2250
7 | Electronics Basin | Backward Extrusion and 4-axis CNC Milling | 30 | 30 | 60 | 150 | 9000
8 | Aluminium Frame | Fiber Glass Laser cutting and Manual Welding | 35 | 25 | 60 | 150 | 9000
9 | Panel | 3-axis CNC Milling | 20 | 10 | 30 | 150 | 4500
10 | Cable Tray | 3-axis CNC Milling | 15 | 10 | 25 | 150 | 3750
11 | Top Foam | 3-axis CNC Contour | 8 | 5 | 13 | 150 | 1950
12 | Lower Pelican Case | Manual Drilling and Reaming | 12 | 10 | 22 | 150 | 3300
13 | M12 Load Cell Cable | Soldering | 10 | 5 | 15 | 150 | 2250

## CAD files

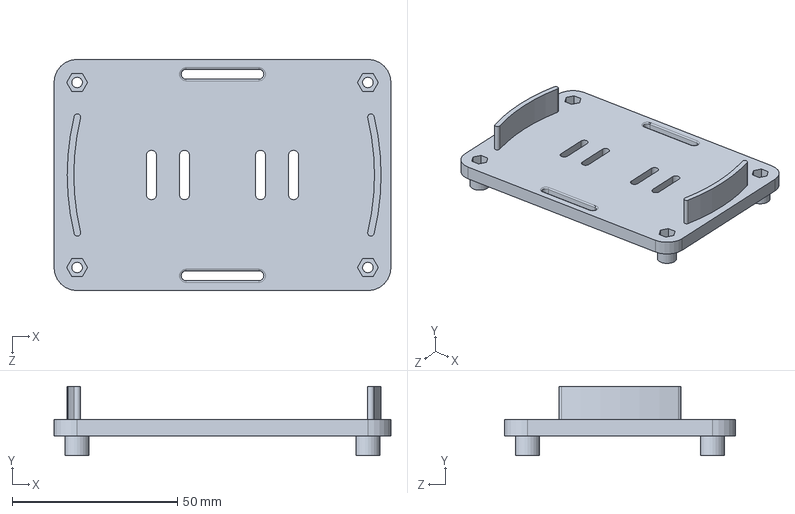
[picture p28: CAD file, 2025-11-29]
2.1 3D Model/Battery Assembly/Battery Cradle kk.SLDPRT
102.0 x 21.0 x 70.0 mm

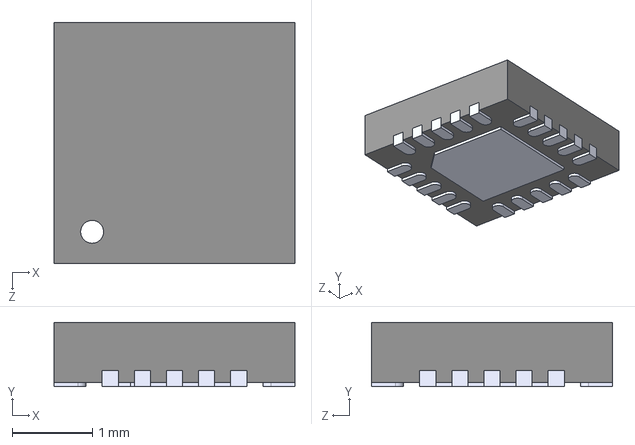
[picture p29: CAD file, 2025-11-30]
2.3 Circuit Diagram/part-lib/ADS127L21IRUKT.STEP
3.00 x 0.8 x 3.00 mm

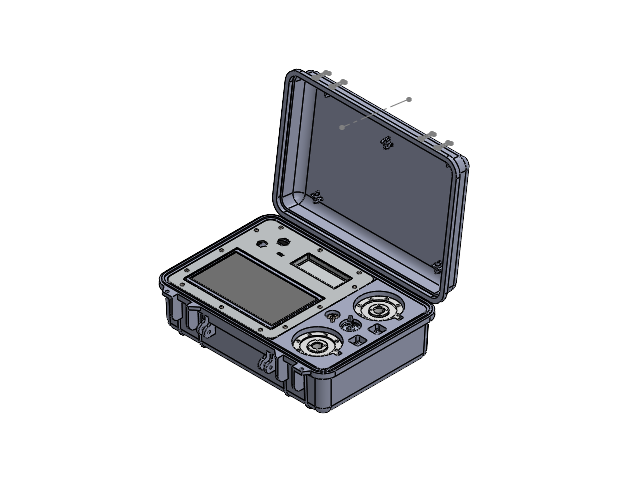
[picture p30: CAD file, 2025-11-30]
2.1 3D Model/sexy boii.SLDASM
1500bot- rev G
1501-931T-CLR
gasket
plain washer small grade a_iso m4 x 28
socket button head screw_iso x 28
hex nut style 1 gradeab_iso x 16
panel
1500-PF
O-Ring
Compartment for Cables n other stuff idk what to call it
Seal For Screen Bezel
Touch Screen
Battery Cradle
Lipo Battery 5000 mAh
Velcro Strap
Load Cell Compartment
LC-40-0003 - 3D CAD load cell pancake 3000 kgf (F3000K)
LC-40-0005 - 3D CAD load cell pancake 250 kgf (F250K)
LC-40-0007 - 3D CAD load cell donut B 20 kgf (E20K)
LC-40-4502 - 3D CAD load cell donut A 45 kgf (D45K)
SA-01-0041 - LC-40-0006 - 3D CAD load cell flat 150 gf (A151)
SA-01-0050 - LC-40-0202 - 3D CAD load cell flat 2 kgf (C202)
M4 x 10 Rivet x 12
Foam Around Aluminum Box
hex tapping screws_iso x 4

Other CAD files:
2.1 3D Model/2025_Project_Team_02_CLOSE.SLDASM
2.1 3D Model/M12 Cable/M12_Assembly.SLDASM
3.1 Technical Drawing/V2/2025_Project_Team_02/Battery in Cradle.SLDASM
2.1 3D Model/2025_Project_Team_02_OPEN.SLDASM
3.1 Technical Drawing/V2/2025_Project_Team_02/Aluminum Box.SLDASM
2.1 3D Model/2025_Project_Team_02_CLOSED.SLDASM
2.1 3D Model/M12 Cable/M12_male/M12_male_wResistor.SLDASM
2.1 3D Model/FVK1.SLDASM
3.1 Technical Drawing/V2/2025_Project_Team_02/Mounted PCB.SLDASM
3.1 Technical Drawing/V2/2025_Project_Team_02/Interior.SLDASM
3.1 Technical Drawing/V2/2025_Project_Team_02/2025_Project_Team_02.SLDASM
3.1 Technical Drawing/V2/2025_Project_Team_02/Top Plate Assembly.SLDASM
3.1 Technical Drawing/V2/2025_Project_Team_02/SS-52400-012.SLDASM
2.1 3D Model/M12 Cable/M12_female/M12_female_attempt-at-auto-features.SLDPRT
2.1 3D Model/M12 Cable/M12_male/M12_male.SLDPRT
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

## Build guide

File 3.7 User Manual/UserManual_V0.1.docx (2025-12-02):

MANUAL VERIFICATION KIT

USER MANUAL

Contents

Safety Precautions

Installation

Cleaning

Repacking & Transport

Product Overview

System Layout

Moving & Handling

Assembling & Preparing

Operating Instructions

Calibration Procedure

Data Logging & Export

Troubleshooting

Technical Specifications

Warranty & Support

Compliance & Certifications

SAFETY PRECAUTIONS

The Innovatest Manual Verification Kit has been designed and manufactured to provide safe and dependable performance. Nevertheless, incorrect handling or operation may result in electrical shock, personal injury, equipment damage, or loss of data. To ensure proper use and long-term reliability, all users must follow the safety requirements described in this section during installation, operation, transportation, and maintenance of the device.

On Safety

Use only the original charging equipment and cables supplied with the unit. If a replacement cable is required, ensure it meets applicable national safety standards. If the charging cable or any part of the power system appears damaged, discontinue use immediately and contact the manufacturer or an authorized Innovatest service provider.

The USB-C charging connector functions as the primary disconnection point for the device. Ensure that the charger and the wall outlet are easy to reach and remain unobstructed.

Operate the device only within the voltage and power limits specified in this manual. If you are uncertain about the conditions of your electrical installation, consult a qualified technician or supervisor.

Do not use overloaded extension cords, uncertified power banks, or visibly damaged charging accessories. Such equipment can cause overheating, electrical shock, or fire.

While the device is connected to a power source, some internal components may remain energized even if the unit itself is switched off. Always unplug the charger before cleaning, transporting, or performing maintenance.

Do Not Open the Device

There are no user-serviceable components inside the electronics module.
Opening the sealed enclosure will void the IP67 protection rating and may expose the user to hazardous voltages.

High internal voltages may remain present even when the device is turned OFF.

If the unit stops functioning correctly, contact Innovatest service personnel.
Do not attempt to open, repair, or modify the internal electronics under any circumstances.

To Avoid Personal Injury

- Place the unit only on stable, flat, and vibration-free surfaces. Unstable positioning may cause the device or connected load cell to fall.
- Transport the system exclusively using the integrated Pelican handle. Never lift the device using cables or connected accessories.
- Avoid striking, dropping, or applying excessive force to any part of the touchscreen or enclosure, as this may damage internal components.
- Do not insert objects into any USB port, ventilation opening, or the load cell connector.
- Keep the equipment away from children and untrained personnel to prevent accidental misuse or injury.

To Prevent Fire, Electrical Shock, or Hazards

- Turn the device OFF and disconnect it from the charger when it will not be used for an extended period.
- Keep liquids, metal objects, and high-voltage tools away from the M12 load cell connector to avoid electrical short circuits and injury.
- Do not use or attach accessories that are not approved for this verification kit, as they can compromise electrical safety and sealing integrity.
- Do not operate the device in environments with open flames, excessive dust, or explosive atmospheres.
- During thunderstorms or electrical storms, avoid touching the charger, USB cables, or load cell cables.
- Avoid high-humidity environments. The device is IP67 rated, but improper cable connections may allow moisture to enter.

Battery and Charging Safety

Never attempt to remove, puncture, or replace the internal battery. Doing so may lead to overheating, fire, or chemical leakage.

Charge the device only with certified USB-C power sources.
If unusual heat, odor, noise, or smoke is detected, immediately disconnect all cables and stop using the device.

Do not leave the device charging unattended for extended periods.

Environmental and Handling Precautions

Ensure all ports and connectors are dry and free of contamination before use.

Do not expose the device to temperatures outside the permitted operating range (0–60°C).
Avoid placing heavy items on the case or applying pressure to the touchscreen.

Before transporting the device, ensure all load cells are properly secured in their designated foam compartments.

Do not close the Pelican case while cables are still attached; doing so may damage wiring or connectors.

Data Protection Safety

Always use the Safe Eject function before removing the USB stick.
Unplugging the storage device prematurely may result in file corruption.

Verify adequate battery level before starting extended measurement or calibration processes.
Unexpected power loss during calibration may corrupt stored data.

INSTALLATION

Correct installation is essential for achieving accurate measurement results and maintaining device safety. Follow the guidelines below when setting up the Innovatest Manual Verification Kit.

Placement and Setup

Place the unit on a stable, flat, and vibration-free surface.
Avoid locations near table edges or where the device may be knocked over.

Fully open the Pelican case and ensure that it remains firmly positioned before touching the touchscreen or connecting cables.

Do not place tools, equipment, or load cells on top of the touchscreen or electronics compartment.

Avoid installation sites with prolonged exposure to direct sunlight, which may cause overheating and reduced display visibility.

Environmental Considerations

Do not place the device near water sources such as wash stations, coolant tanks, or open containers.
Avoid extremely dusty, dirty, or corrosive environments, as metal dust and chemicals can degrade connectors and seals.

Maintain good ventilation around the system. Excessive heat buildup may affect battery life and electronic stability.

Keep the device away from strong electromagnetic interference (e.g., welding equipment, industrial motors, radio transmitters), as these sources can negatively affect measurement accuracy.

Handling the Protective Case

Ensure that the non-slip rubber feet of the case rest securely on the work surface.

Open the case slowly and fully to prevent unnecessary stress on the hinges or accidental displacement of internal components.

Never force the lid closed if any cable is still attached; doing so may damage connectors, load cell ports, or the touchscreen.

Cable Routing and Connections

Route the M12 load cell cable in a safe manner that avoids tripping hazards, sharp bending, or pulling.
Strain on the cable can loosen the connector or damage internal wiring.

Use the strain-relief groove near the connector to minimize unwanted motion during operation.

Keep cables away from sharp tools, heavy objects, or rotating machinery in the work area.

Battery and Power Installation

When charging the device, place it near an easily accessible electrical outlet.
Ensure the USB-C cable is not compressed, stretched, or routed under heavy items.

Avoid installing the unit near heat sources while charging.
Charge the device only within the recommended temperature range (0–60°C).

Load Cell Installation

Before connecting a load cell, inspect the M12 connector pins to ensure they are clean, dry, and undamaged.

Align the connector properly and twist it gently to lock it in place. Forcing the connector may damage the pins.

Route the load cell cable so it does not interfere with the movement of the hardness tester or surrounding equipment.

Do not install load cells on unstable, contaminated, or obstructed fixtures.

Case and Component Protection

The internal foam inserts are designed to secure and protect the load cells. Always place each load cell in its designated compartment before moving or storing the device.

Do not remove or modify foam padding or structural brackets; these components provide shock absorption and help maintain the IP rating.

Avoid operating or storing the device in environments containing oil mist, airborne chemicals, or corrosive vapors, which may degrade seals and enclosure materials.

General Precautions During Installation

- Do not drop tools or accessories onto the touchscreen or electronics panel.
- Avoid positioning the device under shelves or locations where objects may fall onto it.
- If the device is installed in a semi-permanent location, ensure that the lid can still open fully to allow access to the USB port, emergency stop, and connectors.
- Before each use, verify that all mechanical buttons (Power, Emergency Stop) move freely and are unobstructed.

CLEANING

To maintain accuracy and extend the lifespan of the Innovatest Manual Verification Kit, regular cleaning must be performed using the correct methods. Improper cleaning can damage connectors, the touchscreen, or the protective sealing.

General Cleaning Rules

- Power off the device and disconnect the USB-C charging cable before cleaning.
- Never spray liquids directly onto the touchscreen or into any ports.
- Avoid using chemicals such as alcohol, acetone, solvents, or industrial cleaners, as these may degrade seals and plastic components.

Touchscreen Cleaning

- Wipe the touchscreen using a clean, soft, lint-free microfiber cloth.
- If necessary, lightly dampen the cloth with water (never apply water directly to the screen).
- Do not apply excessive pressure to the touchscreen.

Exterior Case Cleaning

- Clean the Pelican case exterior using a damp cloth; mild soap may be used.
- Do not use abrasive pads, brushes, or high-pressure water jets, as these may compromise sealing.

Connector Cleaning

- Ensure all connectors (USB-A, USB-C, M12 load cell port) are dry before use.
- Use low-pressure dry compressed air to remove dust.
- Do not insert metal tools, pins, or sharp objects into connectors.

Internal Components

Do not attempt to clean or open the internal electronics module.
Opening internal components voids the IP67 rating and warranty.

If internal contamination (dust, liquid, corrosion) is suspected, contact Innovatest service support.

Regular Cleaning Frequency

- Daily: Wipe touchscreen, inspect connectors for dust.
- Weekly: Clean exterior case and check seals for debris buildup.
- After harsh environments: Perform a full external cleaning before storing the device.

Proper cleaning maintains measurement accuracy, protects sealing integrity, and extends the service life of the verification kit.

On Repacking

To ensure safe transport and long-term protection of the Innovatest Mobile Force Verification Kit, the unit must be repacked correctly after each use. Improper repacking may lead to damage of load cells, connectors, or internal electronics. Follow the guidelines below when preparing the system for storage or transport.

General Repacking Instructions

- Power OFF the device completely before repacking.
- Disconnect the USB-C charging cable and ensure all ports are free of moisture and dust.
- Remove the load cell cable from the M12 connector before placing the kit into storage.
- Do not store the device while it is still warm from charging or heavy operation; allow it to cool down.

Load Cell Repacking

- Place each load cell inside its dedicated foam compartment. Each compartment is shaped to match the load cell’s geometry; ensure proper alignment to avoid strain on cables or connectors.
- Do not stack load cells or place them loosely inside the case. This may cause internal damage, signal degradation, or calibration drift.
- Ensure that load cell cables are coiled loosely and placed in the designated accessory area. Avoid tight bends or knots that may damage shielding or internal conductors.

Cable and Accessory Storage

- Place all cables (USB-C, USB-A sticks, M12 extensions) inside their marked compartments.
- Do not store cables across the touchscreen or electronics panel. This may cause pressure that damages the display or seals.
- Ensure no small tools or loose objects remain inside the case. During transport, movement may cause scratches, dents, or interference with the electronics module.

Securing the Electronics Module

- Verify that the electronics panel is seated correctly within the aluminium frame and foam supports. There should be no visible gaps or lifted areas.
- Do not apply pressure directly to the screen when closing the case.
- Before closing the lid, ensure that:
  - No cable is sticking out
  - Emergency button is unobstructed
  - USB ports are not blocked by objects

Closing the Protective Case

- Gently lower the Pelican case lid while ensuring no object protrudes beyond the foam.
- Lock both latches firmly until they click. A partially closed case may compromise the IP67 protection and could open during transport.
- Inspect the perimeter gasket for dust or debris. Clean if necessary to maintain water and dust resistance.

Transport Conditions

- Always use the built-in Pelican handle for transport. Do not carry the case by any external cables.
- Avoid exposing the case to severe impacts, crushing loads, or vibration during transport.
- Do not leave the kit in a hot vehicle or direct sunlight for extended periods. Internal temperatures may exceed safe battery limits.
- If transporting by air, ensure compliance with airline lithium-battery regulations. The device should be carried as hand luggage when possible.

Long-Term Storage

- Store the kit in a dry, cool environment between –20°C and 60°C.
- Ensure the battery is charged to 40–60% before long-term storage.
- Avoid storing the device in high-humidity environments.
- Inspect the case seals and foam padding periodically for wear.

PRODUCT OVERVIEW

The Innovatest Mobile Force Verification Kit is a portable, ruggedized measurement system designed to verify forces applied by hardness testing machines in both laboratory and industrial field environments. The system integrates sensing, processing, display, storage, and connectivity functions within a compact IP67-rated Pelican case. This section provides an overview of the unit’s physical layout, components, and essential features.

Front Panel Components

Touchscreen Display

The device features a 10-inch resistive touchscreen centered on the front panel. It supports operation with gloves and remains visible under a wide range of lighting conditions. The display serves as the primary interface for calibration, measurement, data logging, and system navigation.

Power Button

The power button is positioned above the touchscreen, centered horizontally on the front panel. It provides clear tactile feedback and allows the user to turn the system ON or OFF safely.

Emergency Stop Button

The emergency stop button is located on the right side of the front panel, clearly separated from the touchscreen and power button to prevent accidental activation. It allows the user to immediately stop any ongoing measurement or calibration process.

Status LED Indicator

The status LED is positioned directly next to the emergency stop button on the right side of the front panel. The multi-color indicator provides visual feedback on system status, including power state, active measurements, busy conditions, errors, and battery warnings.

Side and External Panel Components

Side Panel (I/O Ports)

All external connectors of the Innovatest Mobile Force Verification Kit are located on the right side panel of the electronics module. This single I/O zone contains:

USB-A Data Export Port

Positioned on the right side of the electronics panel. Used for exporting measurement logs and calibration files.

USB-C Charging Port

Located directly next to the USB-A port on the same right side panel. Serves as the primary charging interface for the internal Li-ion battery.

M12 5-Pin Load Cell Connector

Mounted on the right side panel, grouped with the USB ports. Supports differential signal lines, excitation voltage, and the load-cell identification resistor. The threaded locking mechanism ensures secure attachment during operation.

Internal Components

Battery Module

A high-capacity Li-ion battery pack (≈5000 mAh) provides 8–10 hours of operation. The module is mounted inside the sealed electronics enclosure to maintain IP protection.

Main PCB Assembly

The PCB contains:

- Microcontroller
- 24-bit ADC
- Instrumentation amplifier
- Passive low-pass filters
- Power regulation circuits
- Memory module for data storage

The electronics are mounted on vibration-damped supports to ensure accuracy and reliability in harsh environments.

Aluminium Support Frame

A rigid internal frame holds the electronics panel securely inside the Pelican case. It provides:

- Structural reinforcement
- Shock absorption
- Thermal separation between battery and PCB

Foam Compartments

Precision-cut foam sections store load cells and protect them during transport. Dedicated slots prevent cable strain, connector bending, or contact damage.

Carrying Case (Pelican 1500)

The entire system is integrated into a Pelican 1500 IP67-rated protective case, offering:

- Dust and water ingress protection
- Impact resistance
- Stable handling
- Secure latches and ergonomic carrying handle

The case is designed to keep the device operational even in demanding industrial environments.

SYSTEM LAYOUT

The Innovatest Mobile Force Verification Kit integrates its electronics, connectors, user interface, and power system into a compact, rugged IP67-rated enclosure. This section provides an overview of the physical layout, component arrangement, and functional zones inside and outside the device.

Front Panel Layout

Touchscreen Display

A 10-inch resistive touchscreen centered on the front panel.

Power Button

Positioned directly above the touchscreen, centered horizontally.

Emergency Stop Button

Located on the right side of the front panel, separated from frequently used controls to prevent accidental activation.

Status LED Indicator

Placed immediately next to the emergency stop button on the right side. Provides visual feedback on power state, system activity, errors, and battery warnings.

Side and Rear Layout

USB-A Data Port

Located on the side panel of the electronics module, the USB-A port allows the export of calibration data and measurement logs to external storage devices.

USB-C Charging Port

Positioned near the USB-A port, the USB-C connector is the primary charging interface for the internal Li-ion battery. Its recessed placement protects against accidental impact.

M12 5-Pin Load Cell Port

This connector is used to interface with Innovatest load cells. The port supports:

- Signal+
- Signal–
- Excitation supply
- Ground
- Identification resistor for automatic load-cell recognition

The threaded design ensures secure locking during testing.

Internal Layout

Inside the Pelican case, the system is divided into functional zones:

Electronics Module

A sealed aluminium-mounted module contains:

- Main PCB
- ADC and amplification stages
- Power regulation circuitry
- Internal memory
- Battery pack

This module maintains an IP67 rating, protecting the electronics against dust and moisture.

Battery Compartment

The Li-ion battery is mounted within the electronics enclosure and isolated thermally from the rest of the components. Safety circuitry regulates charging and protects the battery from overcurrent or overvoltage conditions.

Load Cell Storage Area

Precision-cut foam compartments store Innovatest-approved load cells securely during transport. Each load cell has a dedicated slot to prevent connector strain or mechanical stress.

Accessory Storage Zone

Additional compartments hold:

- USB cables
- M12 adapters
- USB sticks
- Documentation These areas keep accessories organized and reduce clutter during field operations.

Pelican Case Layout

The device is housed in a Pelican 1500 IP67-rated case designed for industrial transport and field operations.

Its structural components include:

- Dual-latch locking mechanism
- Pressure-equalizing valve
- Rubber perimeter sealing gasket
- Shock-absorbing foam inserts
- Reinforced carry handle

The case protects the device from:

- Vibration
- Impact
- Water spray or immersion
- Dust and airborne contaminants

Functional Zones Overview

The overall system layout is divided into:

User Interaction Zone

Touchscreen, LED indicator, and primary buttons.

Input/Output Zone

USB-A, USB-C, and M12 load cell connector.

Processing Zone

Main PCB and signal conditioning circuitry.

Power Zone

Battery pack and protective power management circuits.

Storage Zone

Foam compartments for load cells and accessories.

This layout ensures easy operation, safe cable routing, and fast access during calibration or verification procedures.

MOVING AND HANDLING THE KIT

The Innovatest Mobile Force Verification Kit has been designed for portability and safe transportation in demanding environments. To prevent physical injury and protect the internal electronics from damage, follow the guidelines below whenever moving, lifting, or transporting the unit.

Safe Lifting Practices

(Subtitle — Arial 14 Bold)

Use the Built-In Carry Handle

Always lift and carry the system using the integrated Pelican handle. This handle is ergonomically designed to provide a secure grip and minimize strain during transport.

Do Not Lift by Cables or Connectors

Never lift or pull the device using the USB cable, M12 load cell cable, or any attached accessories. Doing so may cause electrical damage, connector deformation, or cable failure.

Keep the Unit Upright

Transport the case in its upright orientation. Avoid carrying it sideways or upside-down, as internal components and stored load cells may shift and sustain mechanical stress.

Handling While the Case Is Open

Do Not Attempt to Move the Unit with the Lid Open

Moving the case while open may cause the lid to slam shut or internal components to shift unexpectedly. Always close and latch the lid before relocation.

Secure Components Before Moving

Ensure that all load cells, cables, and accessories are properly placed in their foam compartments before attempting to reposition the kit.

Avoid Leaning on the Electronics Panel

Do not use the touchscreen or internal frame as a gripping point while repositioning the case. These components are not designed to support lifting forces.

Transport on Industrial Floors

Avoid Dragging the Case

Dragging the device across factory floors may wear down the protective shell and compromise sealing. Always lift the case or use a transport cart for longer distances.

Watch for Tripping Hazards

Ensure that cables connected during calibration or measurement are not pulled or stretched when repositioning equipment around the case.

Keep Away From Heavy Machinery Paths

Avoid placing the kit in areas where forklifts, pallet jacks, or mobile equipment are used, to prevent accidental impact.

Handling During Field Deployment

Protect Against Vibration and Shock

Although the Pelican case provides significant shock absorption, excessive vibration or sudden impacts should be avoided to protect internal electronics.

Avoid Exposure to Extreme Temperatures During Transport

Do not leave the kit in direct sunlight, inside vehicles during hot weather, or in freezing conditions for extended periods. Temperature extremes may affect battery and sensor performance.

Keep the Case Closed in Dusty or Wet Environments

Only open the Pelican case when necessary. Keeping it closed prevents dust, moisture, and airborne contaminants from entering the system.

Short-Distance Handling

For short repositioning movements (within the same room):

- Disconnect any cables.
- Ensure the lid is fully closed.
- Lift the case using both hands if necessary.
- Place the case gently on the new surface to avoid shock impact.

Long-Distance Transport

Transport By Vehicle

Secure the case using straps or place it on a flat, stable surface. Avoid stacking heavy objects on top of it.

Transport By Air

Comply with airline regulations for lithium-ion batteries. In most cases, the device should be transported as carry-on luggage.

Shock Labels (Optional)

For shipment or courier transport, shock indicator labels may be applied to monitor handling conditions.

Inspection After Transport

After moving the kit over long distances or through rough environments:

- Inspect the case for cracks or latch damage.
- Check the seals for dust or debris.
- Verify that load cells are still properly seated.
- Power on the device to ensure normal operation.

Any abnormalities should be reported to Innovatest support before further use.

ASSEMBLING AND PREPARING

The Innovatest Mobile Force Verification Kit is designed for quick setup and reliable operation in both laboratory and industrial environments. This section provides detailed instructions for opening the case, preparing the workstation, connecting load cells, and ensuring the system is ready for use.

Opening the Case

Before operating the system, ensure the protective Pelican case is placed on a stable, flat surface.

Steps:

1. Release both front latches and gently lift the lid.
2. Fully open the case until it reaches its locked hinge position.
3. Visually inspect the internal compartments to confirm all components are correctly seated in the foam inserts.
4. Ensure no loose objects are resting on the touchscreen or electronics panel before proceeding.

Important Notes:

- Do not force the lid open beyond its hinge limit.
- Avoid opening the case in environments with high dust, moisture, or airborne contaminants.

Workstation Preparation

Before connecting any equipment or powering the system, make sure the environment is suitable for accurate measurement.

Recommended Conditions:

- A clean, vibration-free surface
- Ambient temperature between 0°C and 60°C
- No nearby sources of electromagnetic interference (welders, high-power motors, induction heaters)
- Sufficient clearance to fully open the case and route cables safely

Avoid:

- Direct sunlight on the touchscreen
- Oily or contaminated surfaces
- Crowded workspaces where cables may be stepped on or pulled

Inspecting the Components

Before use, verify the condition of all essential components.

Inspect:

- Touchscreen surface (no cracks or deep scratches)
- USB-A port (free of dust and debris)
- USB-C charging port (no bent pins or corrosion)
- M12 5-pin load cell connector (threads clean and undamaged)
- Load cells (cable insulation intact, connectors clean)
- Foam inserts (no deformation affecting component seating)

If any item appears damaged, do not proceed. Contact Innovatest service personnel.

Connecting the Load Cell

The load cell must be connected before calibration or measurement.

Steps:

1. Align the M12 5-pin connector with the port on the electronics module.
2. Carefully push in and twist to secure using the threaded locking mechanism.
3. Ensure the connector is fully tightened by hand—do not use tools.
4. Verify that the cable is routed so it does not interfere with the hardness tester’s moving components.

Warnings:

- Do not force the connector; misalignment can damage pins.
- Do not connect or disconnect the load cell with wet hands.
- Avoid sharp bends or crushing of the cable.

Preparing the Power System

Before powering the system, ensure sufficient battery life for the intended operation.

Check Battery Level:

- Press the power button briefly.
- The LED indicator will display approximate battery status.
- If the battery is low, connect a certified USB-C charger before starting any measurement workflow.

Charging Notes:

- Charge only within the temperature range 0°C–60°C.
- Ensure the USB-C port is clean and dry.
- Do not operate the system during rapid charging if the unit becomes warm.

Preparing the Touchscreen Interface

Before powering on:

- Remove dust using a microfiber cloth.
- Ensure no foreign objects are touching the screen.
- Check that gloves (if used) are clean and dry to ensure proper touchscreen responsiveness.

Initial System Power-On

Once all components are in place:

1. Press the power button for one second.
2. Wait for the boot sequence to complete.
3. The main menu will appear, displaying access to Calibration, Measurement, Data Logging, Settings, and Peak/Hold functions.

If the device fails to start:

- Check battery level.
- Ensure all connectors are uninterrupted.
- Inspect the emergency stop button (must be in the unactivated position).

Ensuring Measurement Readiness

Before beginning calibration:

Confirm:

- The load cell is securely attached.
- The cable is not twisted or tensioned.
- The hardness tester is properly aligned for applying force to the load cell.
- No vibration sources are present near the workstation.
- The touchscreen is responding correctly to inputs.

Only proceed to the calibration or measurement phase once all these conditions are met.

OPERATING INSTRUCTIONS

The Innovatest Mobile Force Verification Kit is designed for intuitive operation in both laboratory and field environments. This section explains the essential functions of the user interface, navigation, measurement modes, and system interactions. Follow these instructions to ensure accurate measurements and reliable long-term performance.

Powering the Device On and Off

Powering On

1. Ensure the load cell is connected and properly seated.
2. Press the Power Button for one second.
3. The system will begin its startup sequence and load the main interface.
4. Once complete, the Main Menu will be displayed.

Powering Off

1. Ensure no measurement or calibration is in progress.
2. Press and hold the Power Button for two seconds.
3. Wait until the screen turns completely dark before closing the Pelican case.

If the system does not power on:

- The battery may be depleted—connect the USB-C charger.
- Verify that the emergency stop button is not locked in the active position.
- Inspect connectors for contamination or damage.

Understanding the Main Menu

After the boot sequence, the Main Menu displays the primary operational functions:

- Calibration
- Measurement
- Peak & Hold
- Data Log
- Settings

A permanent Back button is displayed in the upper-left corner, while the battery indicator is shown on the upper-right side.

Navigation

- Use the touchscreen to select menu items.
- Buttons are sized for glove operation.
- Navigation follows a consistent top-level hierarchy to avoid confusion.

Live Measurement Mode

The Measurement screen displays real-time force readings from the connected load cell.

Displayed Information:

- Current force value
- Unit (N, kN, kgf, gf)
- Live force-versus-time graph
- Load cell identification
- Status messages

Measurement Controls:

- Start / Stop Measurement
- Zero / Tare
- Peak & Hold (shortcut)
- Return to Main Menu

Best Practices:

- Ensure the load cell is free from pre-loads or side forces before starting.
- Keep cables untensioned for accurate readings.
- Avoid touching the load cell during measurement.

Using the Peak & Hold Function

Peak & Hold mode captures the highest recorded force applied during the test.

How It Works:

1. Select Peak & Hold from the Main Menu (or use the shortcut on the measurement screen).
2. Apply force using the hardness tester.
3. The system captures and holds the maximum measured force.
4. The value remains displayed until the user resets the function.

When to Use:

- Hardness tester verification
- Mechanical testing
- Dynamic or impact force monitoring
- Situations where instantaneous peaks must be recorded

Zero and Tare Functions

These functions ensure that measurement starts from a valid baseline.

Zero

- Removes small offsets from the sensor signal.
- Use Zero when no force is applied to the load cell.

Tare

- Used when a known pre-load or fixture weight is present.
- Establishes a new reference point while compensating for external forces.

Warnings:

- Do not press Zero/Tare while the load cell is under significant load.
- Always verify stability before applying Zero/Tare functions.

System Notifications and Status Messages

The device may display the following messages during operation:

- “Load Cell Detected”
- “No Load Cell Connected”
- “Cable Error”
- “Overload”
- “Low Battery”
- “Storage Full”
- “Export Successful”

Always follow the on-screen instructions when a notification appears.

Using the Settings Menu

The Settings section allows the user to adjust preferences and system parameters:

Available Options:

- Measurement units
- Display brightness
- Graph display modes
- Power-saving settings
- System information
- Calibration history
- Factory reset (password protected)

Only authorized personnel should modify advanced system settings.

Emergency Stop Function

The emergency button immediately halts measurement, calibration, or data logging.

When to Use:

- Unexpected force spikes
- Loose fixtures or unstable load conditions
- Hardware malfunction
- Unsafe operator conditions

After activation:

- The system will freeze all operations.
- Restore the button to its normal position before continuing.

Low Battery Operation

If the battery reaches a critical level:

- A warning will appear on the display.
- Measurement functions may be disabled.
- Calibration should not be performed until the device is recharged.

To preserve battery:

- Lower the screen brightness
- Close unused menus
- Disconnect the charger once fully charged

Shutting Down After Use

Before closing the case:

1. Stop all measurements.
2. Turn off the device.
3. Disconnect the load cell if transporting.
4. Coil cables loosely.
5. Inspect the interior for loose items.
6. Close and latch the Pelican case securely.

Following these steps ensures safe long-term operation and maintains environmental sealing.

CALIBRATION PROCEDURE

Calibration ensures that the load cell readings are accurate and traceable. The Innovatest Mobile Force Verification Kit supports multi-point calibration procedures designed for hardness tester verification. Follow the steps below before performing any critical measurements.

Before You Begin

Ensure the following conditions are met:

- The load cell is properly connected and identified by the system
- The device is on a stable, level surface
- No external forces are applied to the load cell
- The battery is sufficiently charged

These steps prevent calibration drift and ensure repeatability.

Starting the Calibration Process

1. Power on the device.
2. From the Main Menu, select Calibration.
3. Confirm the detected load cell model and serial number.
4. Choose the number of calibration points (typically 1–5).

The system will prepare the calibration screen, displaying the target force and stability indicators.

Applying Calibration Forces

At each step:

1. Apply force gradually using the hardness tester or reference system.
2. Hold the force steady when the screen indicates “Apply Load.”
3. The LED or on-screen graphic will confirm when stability is achieved.
4. The system automatically records the force at that point.

Important Notes:

- Do not exceed the rated capacity of the load cell.
- Avoid sudden impact forces when collecting calibration points.
- Ensure no cable movement or vibration during measurement.

Completing All Calibration Points

The system will guide you through each point:

- Move to the next target force when prompted
- Follow the same procedure for stability and acquisition
- If an error or excessive deviation occurs, repeat the step

Once all points are collected, the system calculates the calibration line.

Saving Calibration Data

After the final point:

1. The device displays a summary including linearity and offset.
2. Review the calibration curve for abnormalities.
3. Press Save to store results in system memory.
4. A recommended default filename (timestamp-based) is provided.

Calibration files can later be exported via USB.

Recalibration Recommendations

Perform calibration:

- Whenever the load cell may have been overloaded
- After transportation or shock exposure
- At regular intervals based on organizational quality procedures

Recalibration ensures reliable verification results and maintains traceability.

Short Error Handling

These common issues may occur:

- “Unstable Load” → Reduce vibration, apply force steadily
- “Load Too Low/High” → Adjust applied force closer to target
- “Measurement Noise” → Check cable routing and connector tightness

Most errors resolve by repeating the point under stable conditions.

DATA LOGGING AND EXPORT

The Innovatest Mobile Force Verification Kit stores measurement and calibration data internally and provides options for reviewing, managing, and exporting records. This section explains how to log new data, access stored files, and transfer information to external devices.

Data Logging Overview

The system can record both continuous force measurements and calibration results. Logged data includes:

- Time-stamped force curves
- Peak values
- Calibration points
- Load cell identification
- Operator notes (if entered)

Logging ensures traceability and supports quality-control procedures.

Starting a New Data Log

1. From the Main Menu, select Data Log.
2. Press Start Logging to begin recording.
3. Apply force or perform the required test.
4. Press Stop Logging when finished.

Notes:

- Data is saved automatically after stopping.
- Ensure adequate battery life before long logging sessions.
- Avoid cable movement to maintain clean signal data.

Viewing Logged Data

Stored logs can be accessed from the internal memory.

1. Navigate to Data Log → View Records.
2. Select an entry from the list (sorted by date/time).
3. The system will display:
  - Graph of force vs. time
  - Key measurement statistics
  - Metadata (load cell type, date, etc.)

Short Tip:

Use this review function before exporting to ensure the test captured the desired information.

Deleting Data Logs

To free memory:

1. Select the record you want to delete.
2. Press Delete → confirm when prompted.

Warning:

Deleted files cannot be recovered.

Exporting Data via USB

The system supports exporting stored logs to a USB-stick in a portable data format (typically CSV, TXT, or proprietary structure).

Steps:

1. Insert a USB-stick into the USB-A port.
2. Go to Data Log → Export Data.
3. Choose:
  - Export selected file
  - Export all files
4. Wait for the “Export Successful” message.
5. Use USB Eject before removing the USB-stick.

Important Notes:

- Do not remove the USB device during export.
- If export fails, check the USB-stick format or free space.
- Large files may take longer to transfer.

File Naming and Structure

Exported files include:

- Timestamp-based filenames
- Load cell identification tags
- Calibration or measurement labels

This simplifies long-term organization of verification records.

Troubleshooting During Export (Short)

- USB Not Detected: Check the port and try another USB-stick.
- Export Interrupted: Repeat the export and avoid touching cables.
- Corrupted Files: Ensure proper eject procedure and retry.

TROUBLESHOOTING

This section provides guidance for diagnosing and resolving common issues that may occur during operation of the Innovatest Mobile Force Verification Kit. Most problems can be corrected through simple checks of connectors, cables, or basic system settings. For persistent issues, contact Innovatest support.

Load Cell Detection Issues

Load Cell Not Detected

Possible causes:

- M12 connector not fully tightened
- Pins contaminated or misaligned
- Load cell cable damaged

Solutions:

1. Disconnect and reconnect the M12 connector.
2. Inspect pins for dirt or debris; clean gently if necessary.
3. Verify that the load cell model is supported.
4. Try a different load cell cable if available.

Incorrect or Unstable Load Cell Identification

- Ensure the cable is not under tension.
- Avoid bending the cable sharply near the connector.
- Confirm that no electromagnetic noise sources (welders, motors) are nearby.

Measurement Problems

Unstable Readings

Common causes:

- Cable motion
- Vibration on the workstation
- Electromagnetic interference
- Loose connector

Fixes:

- Stabilize the environment.
- Keep cables still and properly routed.
- Tighten the M12 connector.

Force Values Too Low or Too High

- Zero or Tare may have been used incorrectly
- Applied force not centered on the load cell
- Load cell capacity mismatch

Fix:

- Re-zero with no external loads
- Ensure proper alignment with the hardness tester

No Force Displayed

- Load cell disconnected
- Internal protection activated
- System requires restart

Fix:

- Reconnect the load cell
- Restart the device
- Inspect the load cell cable

Calibration Issues

Calibration Step Fails

Occurs when force is unstable or outside expected limits.

Fix:

- Apply force more gradually
- Hold force steady until system confirms stability
- Ensure no vibration or cable strain

Calibration Curve Looks Incorrect

- Load cell may not be aligned properly
- Incorrect calibration weights or forces used
- Noise in environment

Fix:

- Repeat calibration in a stable environment
- Verify load application method

USB and Data Export Problems

USB-Stick Not Recognized

- USB format unsupported
- Dust in port
- Faulty drive

Fix:

- Use a FAT32-formatted USB-stick
- Clean USB-A port with dry air
- Try another USB device

Export Fails Mid-Transfer

- USB removed too soon
- Storage full
- Large file size

Fix:

- Retry and wait until “Export Successful”
- Perform USB Eject before removal

Display or Interface Issues

Touchscreen Not Responding

- Gloves too thick
- Moisture or dirt on screen
- Software freeze

Fix:

- Clean the screen
- Press the Emergency Stop and restart the device

Screen Too Dim

- Display brightness setting too low
- Strong overhead reflections

Fix:

- Increase brightness in settings
- Tilt the case or adjust lighting

Power and Battery Issues

Device Does Not Turn On

- Battery fully depleted
- Emergency stop engaged

Fix:

- Charge the device for at least 10 minutes
- Release emergency stop and retry

Rapid Battery Drain

- Heavy measurement usage
- Extreme temperature
- Battery aging

Fix:

- Reduce screen brightness
- Avoid cold environments
- Contact service for battery evaluation

Internal Error Messages (Short Explanation)

- “Overload” → Applied force exceeds load cell capacity
- “No Cell Connected” → M12 cable disconnected
- “Storage Full” → Delete or export data
- “Sensor Error” → Cable or connector issue
- “Low Battery” → Recharge immediately

When to Contact Innovatest Support

Contact authorized service if:

- The load cell fails repeatedly
- The electronics module becomes unusually hot
- Battery performance drops severely
- Internal error messages appear consistently
- The device has been dropped or impacted

Do not attempt repairs yourself, as this voids IP67 protection and warranty.

TECHNICAL SPECIFICATIONS

The following technical specifications describe the mechanical, electrical, environmental, and performance characteristics of the Innovatest Mobile Force Verification Kit. All values are based on standard operating conditions and may vary slightly depending on load cell model, environment, and usage.

Mechanical Specifications

Housing and Construction

- Enclosure Type: Pelican 1500
- Rating: IP67 water and dust protected
- Material: High-impact polypropylene case with stainless steel hardware
- Internal Frame: Reinforced aluminium support structure
- Internal Protection: Precision-cut foam inserts for load cells and accessories

Dimensions & Weight

- Total Weight: Approx. 5–6 kg (varies based on load cells included)
- Case Dimensions (L × W × H): Approx. 472 × 362 × 190 mm
- Electronics Module: Compact sealed assembly mounted inside case

Display Specifications

Touchscreen

- Size: 10-inch diagonal
- Type: Industrial-grade resistive touchscreen
- Input Support: Gloves, stylus, bare hand
- Brightness: Adjustable
- Operating Feedback: Single-touch command interface

Electrical Specifications

Power System

- Battery Type: Lithium-ion rechargeable pack
- Capacity: Approx. 5000 mAh
- Typical Runtime: 8–10 hours (depending on measurement activity and screen brightness)
- Charging Method: USB-C
- Charging Time: 1–2 hours (with certified charger)
- Protection Circuits: Overcurrent, overvoltage, temperature, short-circuit

Input/Output Ports

- USB-A: Data export (USB-sticks)
- USB-C: Charging only
- M12 5-Pin Connector (Load cell interface):
  - Excitation Voltage: 5 V or 10 V selectable
  - Signal Input: Differential analog input
  - Identification Pin: Voltage-divider system for load cell recognition

Electronics

- ADC: 24-bit Delta-Sigma high-resolution ADC
- Amplifier: Precision instrumentation amplifier
- Filters: Passive low-pass for noise reduction
- Memory: Internal non-volatile storage for calibration and measurement logs
- Processor: Embedded microcontroller (industrial grade)

Load Cell Compatibility

Supported Load Cells

- Designed for Innovatest force verification load cells
- Minimum Supported Models: 6 distinct load cell types
- Identification Method: Automatic ID via resistor coding
- Connection: Threaded M12 locking connector

Measurement Range

- Typical Supported Range: 10 gf to 3000 kgf
- Overload Protection: Limited by load cell hardware
- Linearity: Based on load cell characteristics

Measurement Performance

Resolution & Accuracy

- Resolution: Dependent on load cell sensitivity (commonly 4 mV/V)
- Measurement Accuracy: Determined by sensor calibration and ADC characteristics
- Data Refresh Rate: Real-time display on measurement screen

Signal Quality

- Differential input design for noise immunity
- Shielded cable compatibility
- Automatic detection of unstable force conditions

Environmental Specifications

Operating Conditions

- Temperature: 0°C to 60°C
- Humidity: 10%–90% (non-condensing)
- Vibration: Device should be used on stable surfaces

Storage Conditions

- Temperature: –20°C to 60°C
- Humidity: 10%–90% (non-condensing)
- Long-term battery storage recommended at 40–60% charge

Software Features

User Interface

- Icon-based navigation
- Multi-language support (if enabled)
- High-contrast layout for industrial visibility

Functional Features

- Multi-point calibration
- Live measurement graph
- Peak & Hold mode
- Data logging
- USB export
- Load cell auto-recognition
- Internal file management

Compliance and Safety

Certifications

(General template, modify based on final university or project requirements)

- Designed according to common industrial safety guidelines
- RoHS-compliant components (where applicable)
- Internal electrical protections for battery safety

WARRANTY AND SUPPORT

The Innovatest Mobile Force Verification Kit is engineered to provide reliable performance during force-verification and calibration tasks. This section outlines the warranty terms, service conditions, and recommended procedures for obtaining technical assistance.

Warranty Coverage

The device and its components are covered under standard Innovatest warranty policies. Warranty coverage applies to:

- Manufacturing defects in materials or workmanship
- Electronic component failures not caused by misuse
- Battery defects within the specified aging and cycle limits
- Functional issues arising during normal, intended operation

Warranty Validity Conditions

The warranty remains valid under the following conditions:

- The device has been used only as intended for force verification
- No unauthorized modifications or repairs have been attempted
- The electronics module has not been opened or tampered with
- The device has not been subjected to impact, liquid intrusion, or extreme environmental abuse
- All components (load cells, cables, accessories) have been handled properly

Exclusions

Warranty does not cover:

- Damage resulting from misuse, improper operation, or negligence
- Mechanical damage caused by drops, crushing, or improper transport
- Battery degradation due to age or prolonged deep discharge
- Damage caused by using non-approved load cells or accessories
- Corrosion or contamination from chemical exposure
- Failures caused by incorrect calibration practices

Service and Repair Process

If the device requires inspection or repair:

1. Contact Innovatest technical support using the information provided below.
2. Provide the device model, load cell type (if applicable), and serial number.
3. Describe the issue in detail, including when it occurs and any error messages displayed.
4. If requested, ship the device in its original Pelican case to prevent damage during transport.

Important Note:

Do not attempt to open or repair the internal electronics module yourself.
Unauthorized access voids the warranty and may compromise IP67 protection.

Technical Support Assistance

Innovatest offers support for:

- System setup and configuration
- Load cell compatibility questions
- Calibration procedure guidance
- Data export issues
- Troubleshooting unexpected readings
- Battery or charging concerns

Support personnel can assist via email, telephone, or remote consultation, depending on availability.

Required Information for Support Requests

To speed up service processing, prepare the following information:

- Device model and serial number
- Load cell type and serial number
- Firmware or software version
- Description of the issue
- Steps already taken to resolve the problem
- Recent calibration or usage history

Including photos or screenshots of error messages accelerates diagnosis.

Replacement Parts and Accessories

Replacement accessories such as:

- Load cell cables
- USB charging cables
- USB-A export drives
- Foam inserts or protective components
- Pelican case hardware

may be obtained through authorized Innovatest distributors.

Contact service before ordering replacement load cells to ensure compatibility.

Returning the Device for Service

If the unit must be shipped:

1. Place the system securely in its foam inserts within the Pelican case.
2. Lock the case and use additional packaging if required by the carrier.
3. Do not ship the device with loose load cells inside the case.
4. Include proof of purchase and a detailed issue report.

Innovatest is not responsible for damage during shipment caused by inadequate packaging.

Out-of-Warranty Service

For devices no longer under warranty:

- Paid service and repair options are available
- Replacement batteries may be offered depending on model
- Load cells can often be recalibrated or replaced

The support team will provide a cost estimate before service begins.

End of Life and Disposal

When the device reaches end-of-life:

- Dispose of lithium-ion batteries according to local environmental regulations
- Do not incinerate or dispose of the device in general waste
- Contact Innovatest for responsible disposal guidance

COMPLIANCE AND CERTIFICATIONS

The Innovatest Mobile Force Verification Kit is designed and manufactured according to commonly accepted industry standards for electrical safety, environmental performance, and electromagnetic compatibility. Although certification status may vary based on prototype or production level, the device follows established guidelines to ensure safe and reliable operation.

General Safety Compliance

The device is designed in accordance with internationally recognized principles for safe operation of electronic measurement equipment. These design principles include:

- Electrical insulation and grounding practices
- Overcurrent and overvoltage protection for the battery
- Proper separation of high- and low-voltage sections
- Safe mechanical design to prevent user contact with hazardous components
- Use of non-flammable enclosure materials

Disclaimer

Formal certification (e.g., CE, UL, CSA) may depend on the final production stage and configuration of the device.
Users should follow all safety precautions and operational guidelines provided in this manual.

Electromagnetic Compatibility (EMC)

The system is designed to minimize conducted and radiated emissions and to resist interference from external electromagnetic sources.

The device follows the principles of:

- EN 61000 family of EMC standards (general reference)
- Shielded cable design to reduce noise
- Differential measurement inputs for improved immunity
- Passive filtering components on the PCB

User Notes:

- Avoid operating the device near strong electromagnetic sources such as welding equipment, high-frequency motors, or induction heaters.
- If abnormal measurement noise occurs, inspect cable routing and reduce EMI exposure.

Environmental Compliance

Where applicable, components used in the system follow environmentally responsible guidelines, including:

- Reduction of hazardous substances in electronics (RoHS-style compliance)
- Use of recyclable materials in the protective case
- Environmentally considerate disposal recommendations

Disposal Requirements

- Do not dispose of electronic components with general waste.
- Follow local regulations for electronic waste (WEEE-style guidance).
- Batteries must be recycled or returned to an appropriate collection facility.

Battery Safety Compliance

The lithium-ion battery pack includes:

- Overcurrent protection
- Overvoltage protection
- Temperature monitoring
- Short-circuit protection

These safety features follow widely adopted international battery safety practices.

Important Notice

Do not attempt to open, modify, or replace the battery.
Incorrect handling may cause fire, chemical leakage, or explosion.

Load Cell and Signal Interface Compliance

The load cell interface is designed according to common industrial measurement signal standards:

- 5 V / 10 V excitation supply
- Differential analog sensing
- Noise reduction through shielding and filtering
- Use of industry-standard M12 connectors

These practices ensure compatibility with standard force measurement devices.

Prototype and Development Compliance Statement

For university, prototype, or research versions of the device:

- The system is intended for controlled environments
- It should be operated only by trained personnel
- It is not intended for medical or life-support applications
- It must not be used in safety-critical production environments without additional certification

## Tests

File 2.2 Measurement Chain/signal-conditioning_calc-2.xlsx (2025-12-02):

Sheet: Gain INA + VGA
Using INA gain of | 100
R2 [kOhm] | 4.99
RT [kOhm] | 20
5V Excitation
Load Cell [kgf] | Sensitivity [mV/V] | Saturated Output [mV] @5V | Required Gain @5V | INA RG [kOhm] | Remaining Gain (VGA) | VGA RF [kOhm] | VGA D (absolute) [-] | VGA D (rounded) [-] | Actual VGA Gain | Gain Error
0.15 | 3 | 15 | 333.33 | 0.1 | 3.33 | 11.64 | 596.1386667 | 596 | 3.332790581 | 0.016%
2 | 2.35 | 11.75 | 425.53 | 0.1 | 4.26 | 16.24 | 831.6949787 | 831 | 4.252598948 | 0.064%
20 | 2.7 | 13.5 | 370.37 | 0.1 | 3.70 | 13.49 | 690.7638519 | 690 | 3.700713928 | 0.081%
45 | 3 | 15 | 333.33 | 0.1 | 3.33 | 11.64 | 596.1386667 | 596 | 3.332790581 | 0.016%
250 | 3.25 | 16.25 | 307.69 | 0.1 | 3.08 | 10.36 | 530.6289231 | 530 | 3.074461423 | 0.080%
3000 | 2.8 | 14 | 357.14 | 0.1 | 3.57 | 12.83 | 656.9691429 | 656 | 3.567635271 | 0.106%
Average | 2.85 | 14.25 | 354.5673528 | 0.1 | 0.1 | 0.1 | 0.1 | 0.1 | 0.1 | 0.1
10V Excitation
Load Cell [kgf] | Sensitivity [mV/V] | Saturated Output [mV] @10V | Required Gain @10V | INA RG [kOhm] | Remaining Gain (VGA) | VGA RF [kOhm] | VGA D (absolute) [-] | VGA D (rounded) [-] | Actual VGA Gain | Gain Error
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

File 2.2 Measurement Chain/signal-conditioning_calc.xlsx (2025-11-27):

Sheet: Gain INA + VGA
Using INA gain of | 100
R2 [kOhm] | 4.99
RT [kOhm] | 20
5V Excitation
Load Cell [kgf] | Sensitivity [mV/V] | Saturated Output [mV] @5V | Required Gain @5V | INA RG [kOhm] | Remaining Gain (VGA) | VGA RF [kOhm] | VGA D (absolute) [-] | VGA D (rounded) [-] | Actual VGA Gain | Gain Error
0.15 | 3 | 15 | 333.33 | 0.1 | 3.33 | 11.64 | 596.1386667 | 596 | 3.332790581 | 0.016%
2 | 2.35 | 11.75 | 425.53 | 0.1 | 4.26 | 16.24 | 831.6949787 | 831 | 4.252598948 | 0.064%
20 | 2.7 | 13.5 | 370.37 | 0.1 | 3.70 | 13.49 | 690.7638519 | 690 | 3.700713928 | 0.081%
45 | 3 | 15 | 333.33 | 0.1 | 3.33 | 11.64 | 596.1386667 | 596 | 3.332790581 | 0.016%
250 | 3.25 | 16.25 | 307.69 | 0.1 | 3.08 | 10.36 | 530.6289231 | 530 | 3.074461423 | 0.080%
3000 | 2.8 | 14 | 357.14 | 0.1 | 3.57 | 12.83 | 656.9691429 | 656 | 3.567635271 | 0.106%
Average | 2.85 | 14.25 | 354.5673528 | 0.1 | 0.1 | 0.1 | 0.1 | 0.1 | 0.1 | 0.1
10V Excitation
Load Cell [kgf] | Sensitivity [mV/V] | Saturated Output [mV] @10V | Required Gain @10V | INA RG [kOhm] | Remaining Gain (VGA) | VGA RF [kOhm] | VGA D (absolute) [-] | VGA D (rounded) [-] | Actual VGA Gain | Gain Error
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

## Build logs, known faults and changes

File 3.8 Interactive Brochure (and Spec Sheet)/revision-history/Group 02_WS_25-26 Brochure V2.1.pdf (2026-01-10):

# VERFICATINATOR


3000

# SEE MORE:

The Verificationinator 3000 is a premier load cell calibration device that works with 6 load cells, promises incredible precision, low noise and easy to use calibration of the load cells. With such a device, laboratory calibration can become a thing of the past, as with high mobility and rugged design, the kit can be taken to any job site in any conditions to verify the force output of Innovatest hardness testers using Innovatest load cells.

# VERF-3000

# Mobile and Portable

accuracy; Factory Durable

Boasting an extremely rugged and shock absorbent design along side IP67 classification, the VERF-3000 can be used in any factory or job site where needed.

# The Verificationinator 3000

# Extreme Precision

With enough precision to be a OIML Class A load cell measuring device, the VERF-3000 can ensure load cells are calibrated to the upmost precision and

The Verificationinator 3000 is mobile and lightweight and can be carried anywhere it is needed.

Weighing only 15kg, it is a revolutionary step in force verification on the go


Main Features The Verificationinator 3000 can be easily used to measure the force values for calibration or testing or routine inspections. The data is plotted on a graph and exportable to a USB stick in a CSV format

# TOUCH SCREEN

SEE HMI:

Real-Time Graphing | Export to CSV


# Long-lasting & Rechargeable


The Verificationinator 3000 has a battery life of over 8 hours to last long enough to work for all measurement needs.

With a Li-ion battery, the device is re-chargeable with thousands of charging cycles for a long product life.

Currently compatible with 6 load cell models and automatically identifies cell to set gain sensitivity for optimal performance.

# Automatic Load Cell Recognition

# SEE LOAD CELLS:

# Spec. Sheet STANDARD

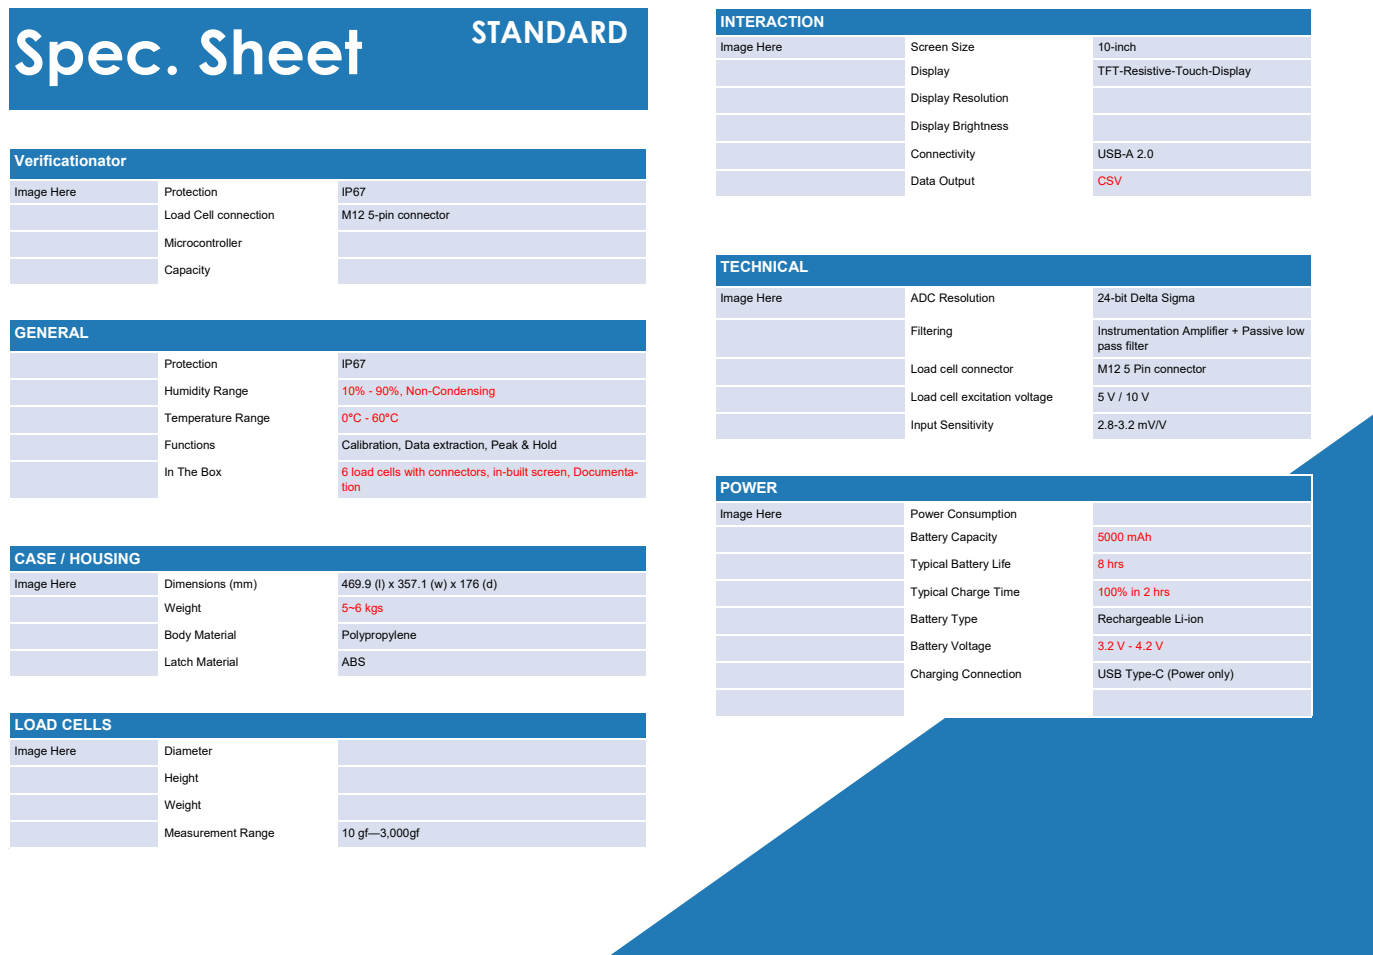
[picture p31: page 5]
Verificationator; Capacity; CASE / HOUSING; GENERAL; INTERACTION; LOAD CELLS; TECHNICAL; Image Here; ADC Resolution; 24-bit Delta Sigma; Filtering; Instrumentation Amplifier + Passive low; pass filter; POWER

Image Here | Screen Size | 10-inch

Display | TFT-Resistive-Touch-Display

Display Resolution

Display Brightness

Connectivity | USB-A 2.0

Data Output | CSV

Image Here | Protection | IP67

Load Cell connection | M12 5-pin connector

Microcontroller

Protection | IP67

Load cell connector | M12 5 Pin connector

Humidity Range | 10% - 90%, Non-Condensing

Load cell excitation voltage | 5 V / 10 V

Temperature Range | 0°C - 60°C

Input Sensitivity | 2.8-3.2 mV/V

Functions | Calibration, Data extraction, Peak & Hold

In The Box | 6 load cells with connectors, in-built screen, Documenta-tion

Image Here | Power Consumption

Battery Capacity | 5000 mAh

Typical Battery Life | 8 hrs

Image Here | Dimensions (mm) | 469.9 (l) x 357.1 (w) x 176 (d)

Typical Charge Time | 100% in 2 hrs

Weight | 5~6 kgs

Battery Type | Rechargeable Li-ion

Body Material | Polypropylene

Battery Voltage | 3.2 V - 4.2 V

Latch Material | ABS

Charging Connection | USB Type-C (Power only)

Image Here | Diameter

Height

Weight

Measurement Range | 10 gf—3,000gf

Development Team:

Ahmad Zeaiter

Abhinav Kothari

Justin Julius Chin Cheong


Wasim Ahmed Mohammed Al Abashi

Okan Can Meral

Contact Person:

abhinav.kothari@hsrw.org

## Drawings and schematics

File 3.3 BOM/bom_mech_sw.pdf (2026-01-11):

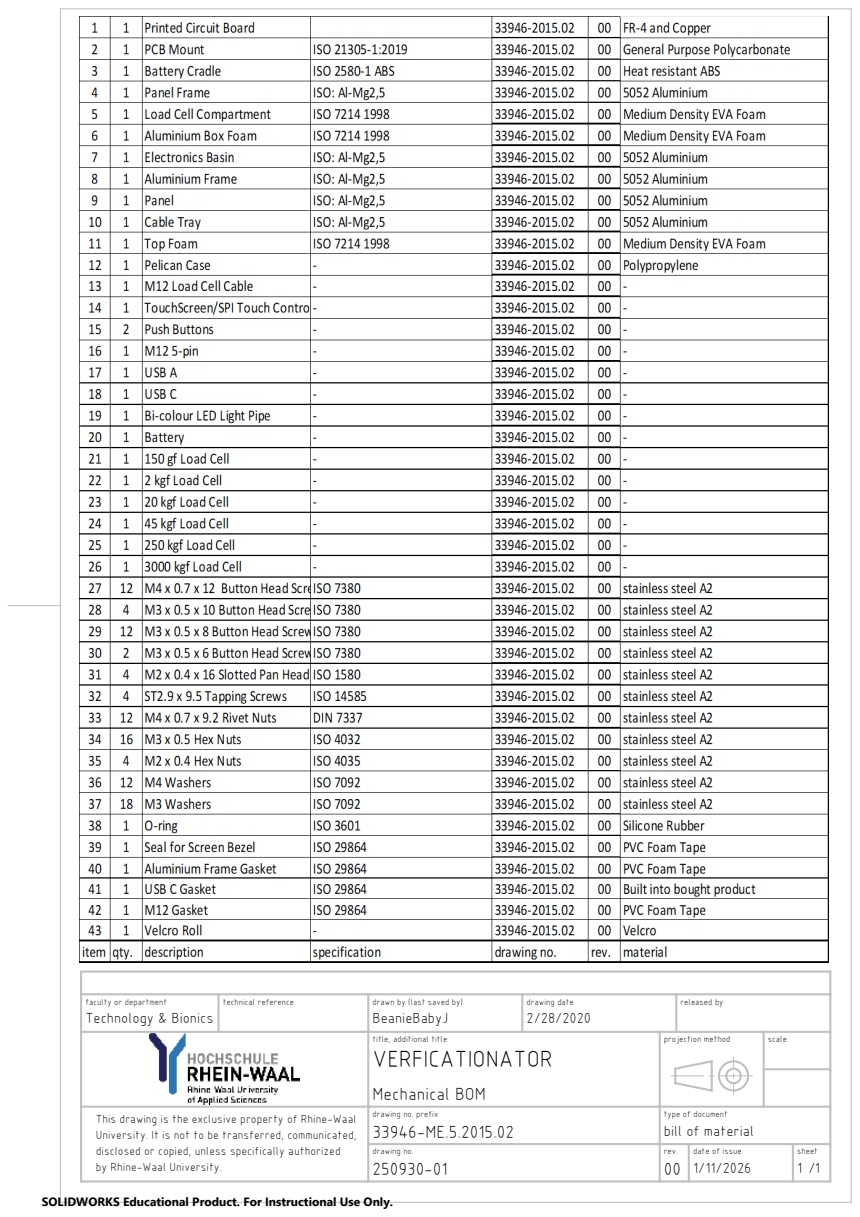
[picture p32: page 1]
drawn by (last saved by); drawing date; released by; drawing no. prefix; type of document; rev.; date of issue; sheet; Mechanical BOM; drawing no.; projection method; technical reference

faculty or department
Technology & Bionics

title, additional title

This drawing is the exclusive property of Rhine-Waal
University. It is not to be transferred, communicated,
disclosed or copied, unless specifically authorized
by Rhine-Waal University.
SOLIDWORKS Educational Product. For Instructional Use Only.

bill of material

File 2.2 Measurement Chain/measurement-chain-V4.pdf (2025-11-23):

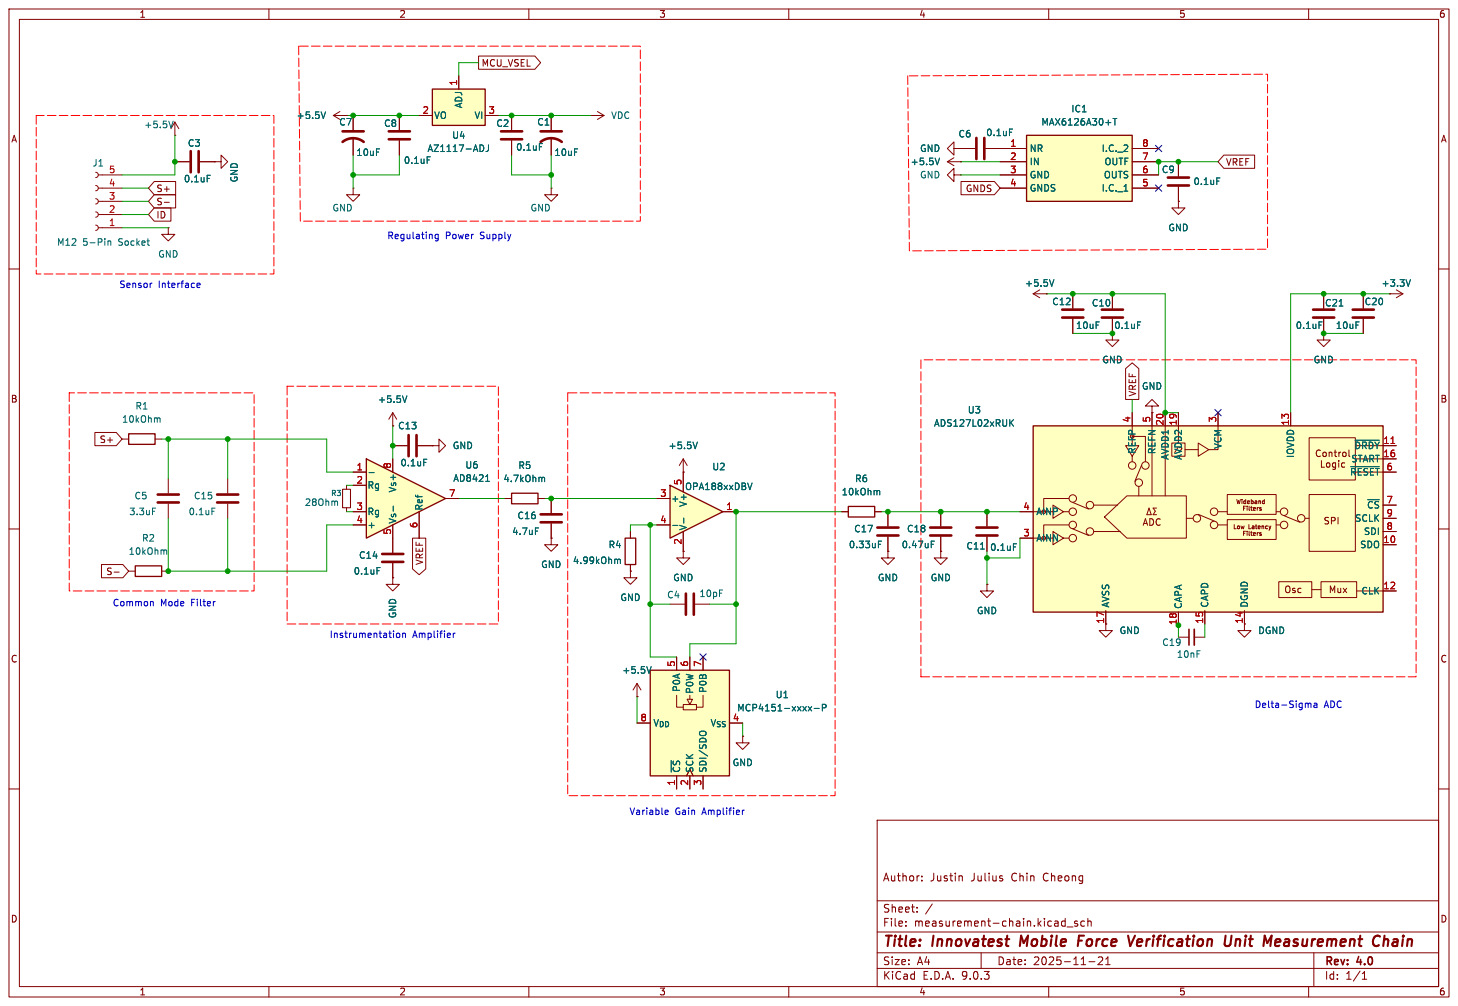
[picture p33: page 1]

3 DGND 14 IOVDD 13
File: measurement-chain.kicad_sch Sheet: / Author: Justin Julius Chin Cheong C18

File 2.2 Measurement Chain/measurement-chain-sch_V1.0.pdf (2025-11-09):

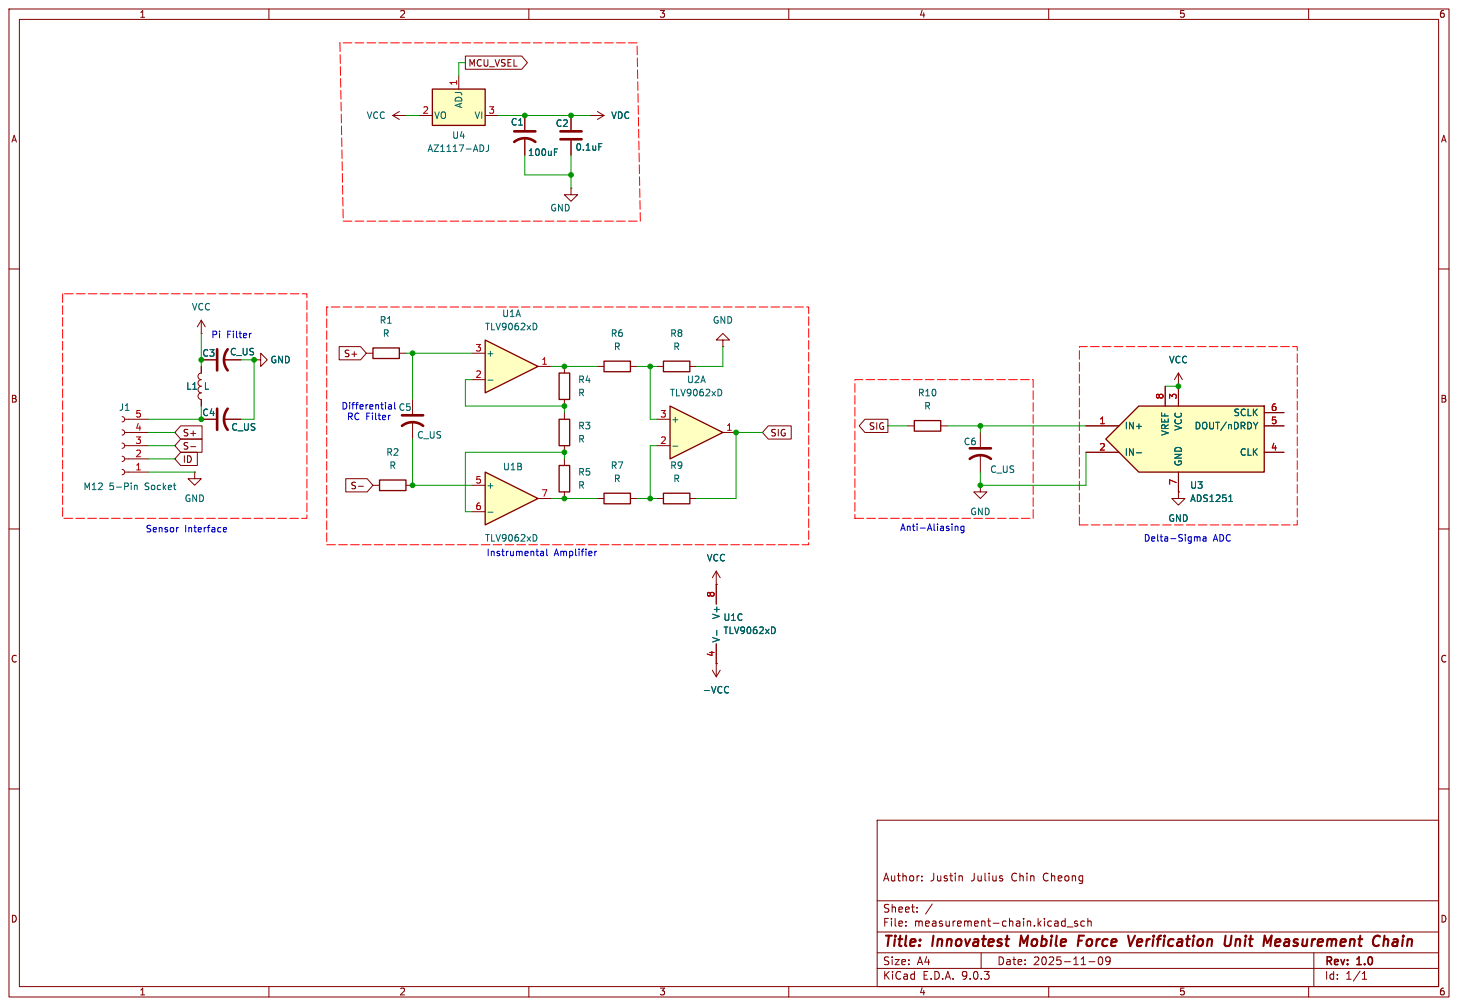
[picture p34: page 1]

7 SCLK 6 DOUT/nDRDY 5 CLK 4 U3ADS1251 VI 3 ADJ 1 VO 2 U4 AZ1117-ADJ

7 SCLK 6 DOUT/nDRDY 5 CLK 4 VCC

File: measurement-chain.kicad_sch Sheet: / Author: Justin Julius Chin Cheong R3 R

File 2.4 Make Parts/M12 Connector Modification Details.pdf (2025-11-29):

E E

A A

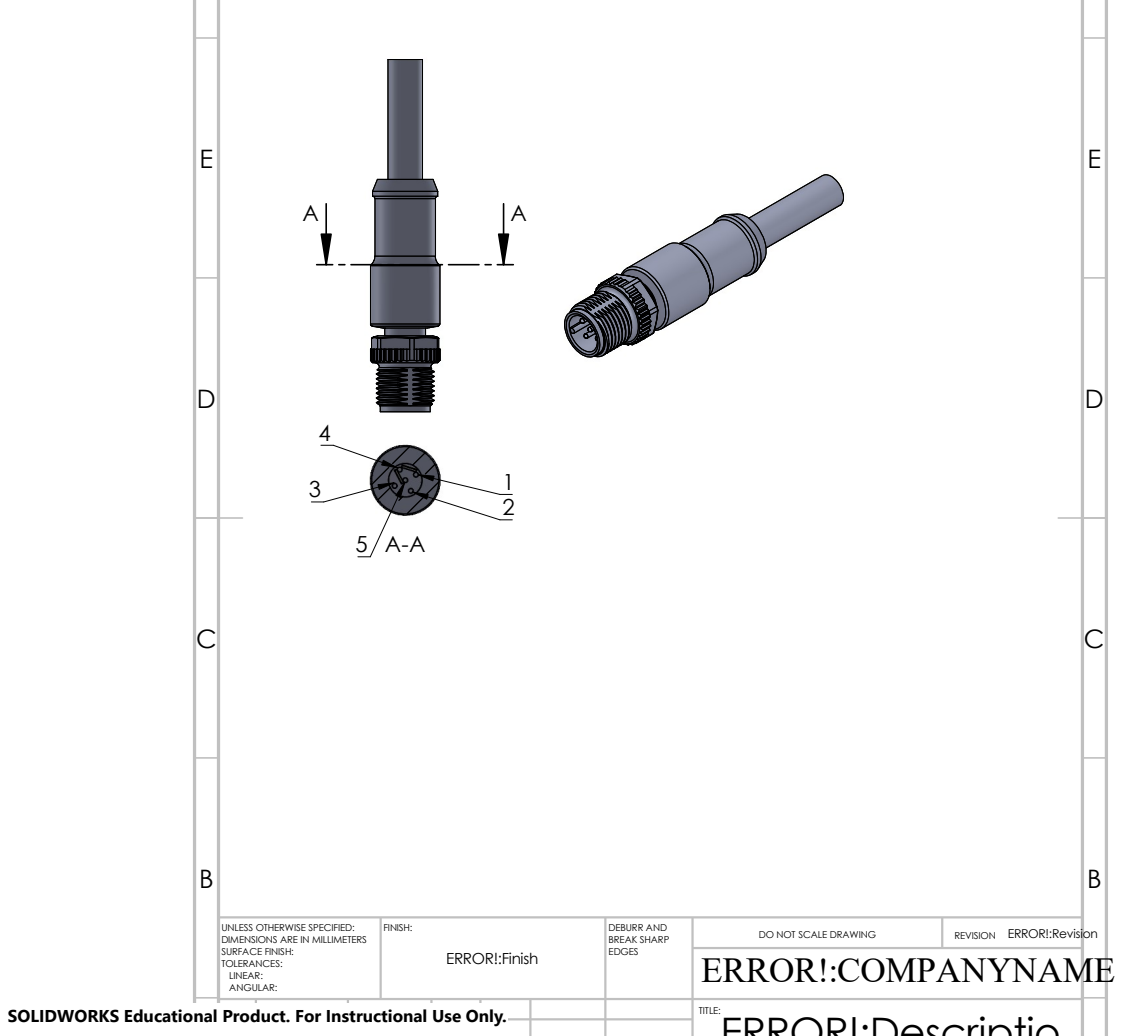
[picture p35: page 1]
BREAK SHARP; DRAWN; ERROR!:COMPANYNAME; ERROR!:DrawnDate; FINISH:; EDGES; NAME; SIGNATURE; DATE; DO NOT SCALE DRAWING; REVISION; TITLE:; ERROR!:Finish; ERROR!:DrawnBy; DEBURR AND; ERROR!:Descriptio; ERROR!:Revision

UNLESS OTHERWISE SPECIFIED:
DIMENSIONS ARE IN MILLIMETERS
SURFACE FINISH:
TOLERANCES:
LINEAR:
ANGULAR:

SOLIDWORKS Educational Product. For Instructional Use Only.

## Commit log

2025-11-09 File Migration
    [Group Project Deliverables 283d787e775c80a0b74bd2d4a6fbd78c.csv, Group Project Deliverables 283d787e775c80a0b74bd2d4a6fbd78c_all.csv, Group-Project_WS25-26_(Ga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]
2025-11-09 Measurement Chain Schematic V1.0
    [measurement-chain.kicad_pcb, measurement-chain.kicad_sch]
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2025-11-14 minor updates to schematic
    just added more decoupling caps
    [measurement-chain.kicad_sch]
2025-11-15 Measurement Chain Sch V2
    [measurement-chain-V1.kicad_sch, measurement-chain-V2.kicad_sch, signal-conditioning_calc.xlsx]
2025-11-18 additional stuff from Okan
    [Requirements_Manual_for_“Buy”_Parts_Tables.xlsx]
2025-11-19 Added VGA to solve the gain problem
    [measurement-chain-V2.kicad_sch, measurement-chain.kicad_sch]
2025-11-20 Minor Updates
    [measurement-chain.kicad_sch, signal-conditioning_calc.xlsx]
2025-11-20 Updates to Measurment Chain + Current Calc
    [measurement-chain-V3.kicad_sch, signal-conditioning_calc.xlsx]
2025-11-20 3D Parts, Models and Assembly
    [1500-PF.SLDPRT, 1500bot- rev G.SLDPRT, 1501-931T-CLR.SLDPRT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]
2025-11-20 Peak-to-Peak Noise Estimate
    [signal-conditioning_calc.xlsx]
2025-11-21 Switching the ADC
    - i decided to use the ADS127L21 instead as it has a isolated digtial supply line and digital filters
    [measurement-chain-V4.kicad_sch, signal-conditioning_calc.xlsx]
2025-11-21 idek part 2
    [signal-conditioning_calc.xlsx]
2025-11-21 Sig fig in Excel
    [signal-conditioning_calc.xlsx]
2025-11-23 Explode views created
    [Battery in Cradle.SLDASM]
2025-11-23 Updated Aluminum Box Assembly
    [Aluminum Box.SLDASM, Basin.SLDPRT, M3x8 7380.SLDPRT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]
2025-11-23 Final Noise Calculations
    [signal-conditioning_calc.xlsx]
2025-11-23 PCB MOUNT
    [Aluminum Box.SLDASM, Board Mount.SLDPRT, Double Tape.SLDPRT]
2025-11-25 Updated Pelican Case
    Missing:
    Pelican 1500 Lid, Handel and Hinges
    Cutouts for M12 & USB-C
    PCB Board
    All Ports
    Screen
    [1500bot- rev G.SLDPRT, Aluminum Box.SLDASM]
2025-11-26 Presentable Signal Calc
    - I just made the spreadsheet nicer
    [signal-conditioning_calc.xlsx]
2025-11-26 separate parts for panel plate
    [Aluminum Box Pt 1.SLDPRT, Aluminum Box.SLDASM]
2025-11-26 1 file missing mb
    [Compartment for Cables n other stuff idk what to call it.SLDPRT]
2025-11-26 First BS Brochure
    [signal-conditioning_calc.xlsx]
2025-11-27 lots
    check out top plate assembly
    [1500-PF.SLDPRT, Aluminum Box Pt 1.SLDPRT, Compartment for Cables n other stuff idk what to call it.SLDPRT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]
2025-11-27 3D Print models
    [Battery Cradle.STL, Board Mount.STL]
2025-11-28 Make parts finishing changes
    Includes more screenshots, change to screen flange for easier manufacturing
    [Aluminum Box Pt 1 - Copy.SLDPRT, Mounted Screen.SLDASM, Screen Flange v2.SLDPRT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]
2025-11-28 M12 Cables
    - added some M12 cables, might be usable
    [77_2529_0000_50705-0200.SLDPRT, 99_3442_458_05.SLDPRT, M12_Assembly.SLDASM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]
2025-11-28 PCB Changes
    [Board Mount.SLDPRT, Board Mount.STL]
2025-11-28 Circuit Diagram Project in KiCAD
    [Inoovatest.kicad_pcb, Inoovatest.kicad_sch, M12_Assembly.SLDASM]
2025-11-28 Minor tweaks
    [Board Mount.SLDPRT, Compartment for Cables n other stuff idk what to call it.SLDPRT]
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2025-11-28 Adding Measurement Chain to Schematic
    - added measurement chain as well as the switching of the excitation voltages
    [Inoovatest.kicad_sch, MCU_and_display.kicad_sch, battery-management.kicad_sch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]
2025-11-29 M12 Connectors
    - found some decent M12's w/ 3D models
    [1436563.stp, 99_0437_110_05.SLDPRT, M12_Assembly_V2.SLDASM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]
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2025-11-29 Views for modification of M12
    [M12_male_wPins.SLDPRT, M12_male_wResistor.SLDASM, M12_male_wResistor.SLDDRW]
2025-11-29 Battery cradle assembly updated
    [Battery in Cradle.SLDASM]
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2025-11-30 Final Schematic
    - made the schematic as pretty as possible
    [Inoovatest-2.kicad_sch, Inoovatest-3.kicad_sch, Inoovatest-4.kicad_sch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]
2025-11-30 added most of the footprints
    [ADS127L21IRUKT.STEP, Inoovatest_Sub.kicad_sch, MCU_and_display.kicad_sch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]
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2025-11-30 Ports Buttons PCB Missing
    [1500-PF.SLDPRT, Aluminum Box Pt 1.SLDPRT, Aluminum Box Pt 2.SLDPRT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]
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2025-11-30 3D Models for electrical parts
    - added all the 3D models for ports
    - created necessary footprints
    [1436563.stp, Inoovatest.kicad_sch, Inoovatest_Sub.kicad_sch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]
2025-11-30 Photo changes, material of panel frame updated
    [1500-PF.SLDPRT, Battery Cradle.STL]
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2025-12-01 PCB Routing Almost Done
    [Inoovatest.kicad_pcb, Inoovatest.kicad_sch, Inoovatest_Full.kicad_sch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]
2025-12-01 fixed handle
    [Case Handle.SLDPRT, Handle Rod.SLDPRT, Interior.SLDASM]
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2025-12-01 Schematic Export to the Document
    - Wassim's annotations and some extra exported and added to the word document
    [Inoovatest_Full.kicad_sch, Inoovatest_Sub.csv, Inoovatest_Sub.kicad_sch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]
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2025-12-02 Minor Updates
    - changed the optocoupler since it was a bit outdated
    - reworked battery estimate and it's still only 7 hours
    - from Okan: 2nd draft of User Manual
    [A4.SLDASM, A5.SLDASM, Inoovatest_Full.kicad_sch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]
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2025-12-02 PCB Model Final (hoffentlich)
    [Inoovatest_Sub.kicad_pcb, signal-conditioning_calc-2.xlsx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]
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2025-12-11 Production Planning Calc
    Almost done with the calculations, just some changes should be made for machine estimate and production times
    [Group 02_WS_25-26 M3 Prodution Planning.xlsx, production_time_estimates.xlsx]
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2025-12-12 Production Planning Draft Done
    [Group 02_WS_25-26 M3 Prodution Planning.xlsx]
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2026-01-11 drawing and flow chart done
    [1500-PF.SLDPRT, 1500bot- rev G.SLDPRT, 1500bot- rev G.STEP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]
2026-01-11 Finishing cost calculation and export to pdf
    [Group 02_WS_25-26 M3 Prodution Planning.xlsx, Innovatest_Cost_Check_Spreadsheet.xlsx]
2026-01-12 final commit
    - project close-out
    - final version of the report
    - adjustments to deliverables for final versions
    [Inoovatest.kicad_sch]
